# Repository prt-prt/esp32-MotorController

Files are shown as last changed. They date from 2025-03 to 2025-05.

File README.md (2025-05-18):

# ESP32 Motor Controller

A collection of motor control implementations for the ESP32-S2 Mini with DRV8833 motor driver.

## Version Overview

### v1: Basic Test
- Simple motor test sequence
- Basic forward/backward/turn movements
- No fault detection

### v2: Mode System
- Multiple movement modes (wander, rotate, test)
- Mode switching logic
- Basic error handling

### v3: Power Management
- Improved power handling
- Speed ramping
- Basic fault detection
- Reduced motor speeds

### v4: Organic Movement
- Slow, rock-like movement patterns
- Advanced fault detection
- PWM-based motor control
- Random movement generation
- Detailed debugging

### v5: Simple Forward Test
- Continuous forward movement
- Basic PWM control
- Minimal code for testing
- No mode switching or complex logic

### v6: All Directions Test
- Tests all motor directions sequentially
- Basic PWM control
- Auxiliary pin control (GPIO39)
- Cycle between directions automatically

## Hardware
- ESP32-S2 Mini (Lolin)
- DRV8833 Motor Driver
- 2 DC Motors
- Power Supply (5V recommended)

## Pin Configuration
- Motor A: GPIO11 (IN1), GPIO9 (IN2)
- Motor B: GPIO7 (IN1), GPIO5 (IN2)
- Fault Pin: GPIO12
- LED: GPIO15

## Project Structure

This project is organized into two versions:
- **v1**: Uses the ESP32-CAM and L298N motor driver (older, traditional driver)
- **v2**: Uses the ESP32-S2 Mini and DRV8833 motor driver (more efficient, modern setup)

Each version contains its own complete implementation for its respective hardware. For detailed wiring and implementation specifics, see the WIRING.md file in each subproject folder.

## Hardware Requirements

### Common Components for Both Versions
- 2-wheel drive robot car chassis with DC motors
- Jumper wires
- Small breadboard (optional, for cleaner wiring)

### Version Specific Components
- **v1**: 
  - ESP32-CAM development board
  - L298N dual H-bridge motor driver ([detailed documentation](v1/WIRING.md))
  - MP1584EN buck converter module (for power regulation)
  - Power supply for motors (battery pack/power bank)

- **v2**: 
  - Wemos ESP32-S2 Mini development board
  - DRV8833 dual H-bridge motor driver ([detailed documentation](v2/WIRING.md))
  - 5V powerbank with USB output
  - USB splitter/hub or adapter
  - USB in-line power switch (for global power control)
  - Step-up converter (boosts 5V from powerbank to 6V for motors)

### Power Supply Architecture Differences

The v1 and v2 versions use different power supply approaches:

**v1 Power Supply:**
- Battery/power source → MP1584EN buck converter → ESP32-CAM (5V)
- Battery/power source → L298N motor driver (higher voltage)

**v2 Power Supply:**
- Powerbank USB output → Global power switch → USB splitter/hub
  - First output: USB-C connection to ESP32-S2 Mini (direct connection)
  - Second output: 5V to Step-up converter → DRV8833 motor driver (6V)

The v2 setup uses a true global power switch that controls the entire system with a single switch, turning both the microcontroller and motors on/off together.

## Hardware Comparison

### Microcontroller Comparison
| Feature | v1: ESP32-CAM | v2: ESP32-S2 Mini |
|---|---|---|
| USB Connection | External programmer required | Built-in USB-C port |
| Size | Larger | Compact |
| Power Input | 5V via pins | Direct USB-C |
| Programming | Via serial adapter | Native USB |
| Unnecessary Features | Camera module | None |
| Form Factor | Less robot-friendly | Ideal for robotics |

### Motor Driver Comparison
| Feature | v1: L298N | v2: DRV8833 |
|---|---|---|
| Efficiency | ~70% | >90% |
| Control Pins | 6 total | 4 total |
| Heat Generation | High | Low |
| Size | Large | Compact |
| Control Method | Enable + Direction pins | PWM on all pins |

### Power Control Comparison
| Feature | v1 Approach | v2 Approach |
|---|---|---|
| Power Switch | Controls motors only | True global control (entire system) |
| Power Source | Separate paths | Single source with distribution |
| Wiring Complexity | More complex | Simplified with USB connectivity |
| Development Mode | ESP32 always on | System fully controlled by one switch |

For detailed pin connections, wiring diagrams, and implementation specifics, see:
- [L298N Wiring & Implementation Guide](v1/WIRING.md)
- [DRV8833 Wiring & Implementation Guide](v2/WIRING.md)

## Software Setup

This project uses PlatformIO for development and deployment:

1. Install [Visual Studio Code](https://code.visualstudio.com/)
2. Install the [PlatformIO extension](https://platformio.org/install/ide?install=vscode)
3. Clone or download this repository
4. Open either the v1 or v2 project folder in VS Code
5. Build and upload the project using PlatformIO

### V2 Programming Advantage
The v2 version with ESP32-S2 Mini can be programmed directly via USB-C connection without additional hardware, making development and testing significantly easier. During development, you can disconnect the powerbank and connect the ESP32-S2 Mini directly to your computer.

## Features

### Movement Modes

The robot car supports three different movement modes:

1. **Test Mode**: Demonstrates basic movements in a sequence
2. **Wander Mode**: Robot randomly wanders with organic movements
3. **Rotate Mode**: Robot slowly rotates around its axis

By default, the robot switches between Wander Mode and Rotate Mode every 30 seconds.

### Basic Movement Functions

The code includes the following standard movement functions:

- `moveForward(speed)`: Moves the robot forward
- `moveBackward(speed)`: Moves the robot backward
- `turnLeft(speed)`: Turns the robot left
- `turnRight(speed)`: Turns the robot right
- `stopMotors()`: Stops all motor movement

### Differential Steering

Advanced movement control is achieved through differential steering:

- `moveDifferential(leftSpeed, rightSpeed)`: Allows independent control of each wheel
- `curveLeft(leftSpeed, rightSpeed)`: Creates curved left movement
- `curveRight(leftSpeed, rightSpeed)`: Creates curved right movement

### Speed Control

All movement functions support variable speed control through PWM, with speed values ranging from 0 (stop) to 255 (full speed).

## Movement Modes in Detail

### Test Mode

Cycles through a series of basic movements to test motor functionality:
1. Forward → Stop → Backward → Stop → Left turn → Stop → Right turn → Stop

### Wander Mode

Implements organic, randomized movement with varying speeds and paths:
- Straight forward movement
- Gentle left and right curves
- Sharp left and right curves
- 180° spin turns
- Backward movement
- Random stops

### Rotate Mode

Performs a slow, controlled rotation around the robot's center:
- Rotates in a random direction (left or right)
- Changes direction every 10 seconds
- Uses reduced speed for careful rotation

## Customization

You can customize the pin assignments at the beginning of the `motor_control.cpp` file if you need to use different GPIO pins on your microcontroller.

To implement additional movement modes or alter the existing ones, refer to the corresponding mode files in the `src` directory.

## Troubleshooting

Basic troubleshooting tips are included in the WIRING.md file for each version:
- [L298N Troubleshooting](v1/WIRING.md#troubleshooting)
- [DRV8833 Troubleshooting](v2/WIRING.md#troubleshooting)

## Project Structure

For each version (v1 and v2):
- `platformio.ini`: PlatformIO configuration
- `WIRING.md`: Detailed wiring and implementation documentation
- `include/motor_control.h`: Header file for motor control functions
- `include/movement_modes.h`: Defines the movement modes enum
- `include/test_mode.h`: Header for test mode
- `include/wander_mode.h`: Header for wander mode
- `include/rotate_mode.h`: Header for rotate mode
- `src/motor_control.cpp`: Motor control functions implementation
- `src/main.cpp`: Main program with setup, loop, and mode switching logic
- `src/test_mode.cpp`: Test mode implementation
- `src/wander_mode.cpp`: Wander mode implementation with organic movement
- `src/rotate_mode.cpp`: Rotate mode implementation

## License

This project is open source and available under the MIT License.

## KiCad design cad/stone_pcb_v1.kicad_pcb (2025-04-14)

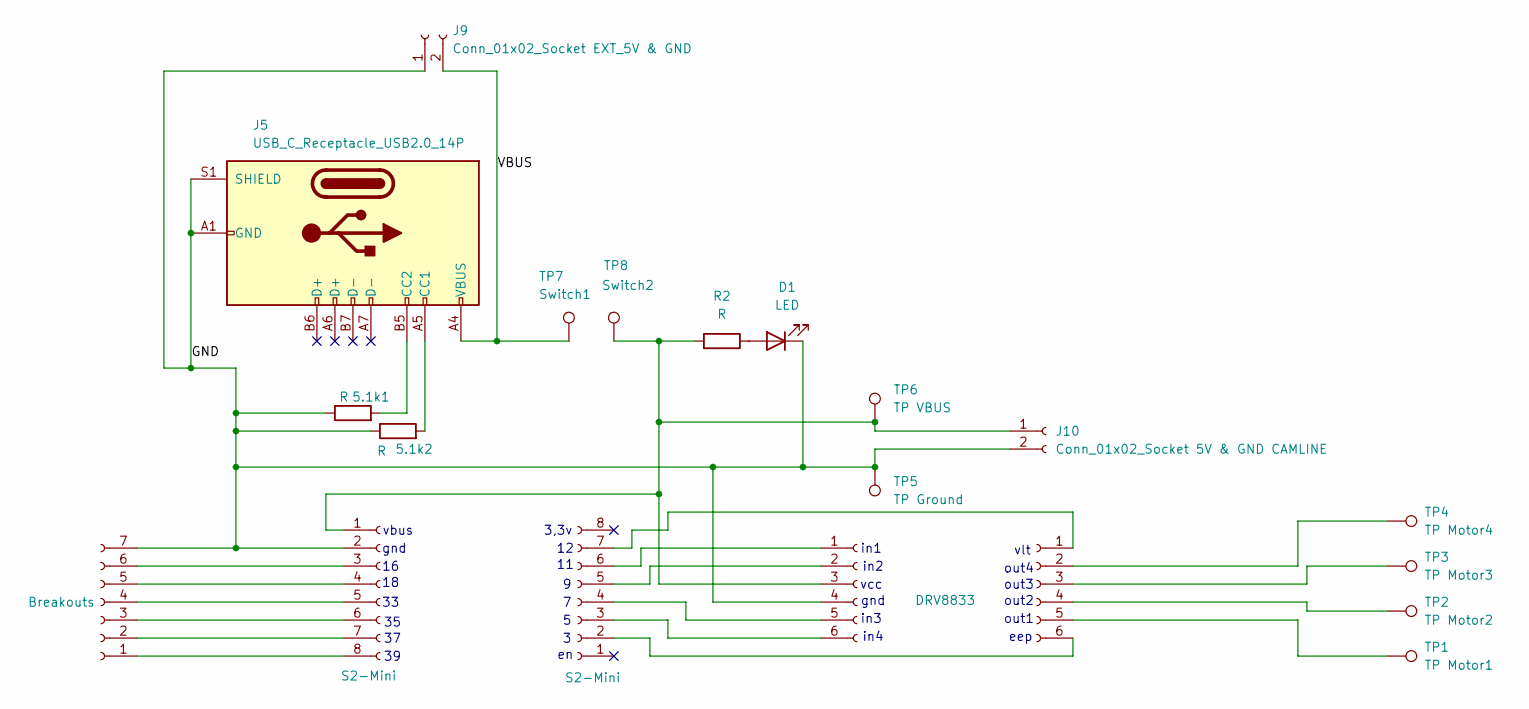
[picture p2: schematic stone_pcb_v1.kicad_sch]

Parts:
5.1k1, 5.1k2: R; R_Axial_DIN0204_L3.6mm_D1.6mm_P7.62mm_Horizontal
D1: LED; LED_D5.0mm
J1: PinSocket_1x06_P2.54mm_Vertical
J2: DRV8833; PinSocket_1x06_P2.54mm_Vertical
J5: USB_C_Receptacle_USB2.0_14P; USB_C_Receptacle_HRO_TYPE-C-31-M-12
J6, J8: S2-Mini; PinSocket_1x08_P2.54mm_Vertical
J7: Breakouts; PinSocket_1x07_P2.54mm_Vertical
J9: Conn_01x02_Socket EXT_5V & GND; PinSocket_1x02_P2.54mm_Vertical
J10: Conn_01x02_Socket 5V & GND CAMLINE; PinSocket_1x02_P2.54mm_Vertical
R2: R; R_Axial_DIN0204_L3.6mm_D1.6mm_P7.62mm_Horizontal
TP1: TP Motor1; TestPoint_Pad_D2.0mm
TP2: TP Motor2; TestPoint_Pad_D2.0mm
TP3: TP Motor3; TestPoint_Pad_D2.0mm
TP4: TP Motor4; TestPoint_Pad_D2.0mm
TP5: TP Ground; TestPoint_Pad_D2.0mm
TP6: TP VBUS; TestPoint_Pad_D2.0mm
TP7: Switch1; TestPoint_Pad_D2.0mm
TP8: Switch2; TestPoint_Pad_D2.0mm

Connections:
/GND: 5.1k1.1, 5.1k2.1, D1.1 (K), J2.4, J5.A1 (GND), J5.A12 (GND), J5.B1 (GND), J5.B12 (GND), J5.S1 (SHIELD), J6.2, J7.7, J9.1, J10.2, TP5.1
/VBUS: J5.A4 (VBUS), J5.A9 (VBUS), J5.B4 (VBUS), J5.B9 (VBUS), J9.2, TP7.1
unnamed: D1.2 (A), R2.1
unnamed: J1.1, J8.7
unnamed: J1.2, TP4.1
unnamed: J1.3, TP3.1
unnamed: J1.4, TP2.1
unnamed: J1.5, TP1.1
unnamed: J1.6, J8.2
unnamed: J2.1, J8.6
unnamed: J2.2, J8.5
unnamed: J2.5, J8.4
unnamed: J2.6, J8.3
unnamed: 5.1k2.2, J5.A5 (CC1)
unnamed: 5.1k1.2, J5.B5 (CC2)
unnamed: J6.3, J7.6
unnamed: J6.4, J7.5
unnamed: J6.5, J7.4
unnamed: J6.6, J7.3
unnamed: J6.7, J7.2
unnamed: J6.8, J7.1
unnamed: J2.3, J6.1, J10.1, R2.2, TP6.1, TP8.1

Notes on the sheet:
out2
in4
eep
in2
gnd
in1
vbus
out3
vlt
out4
3,3v
in3
out1
vcc

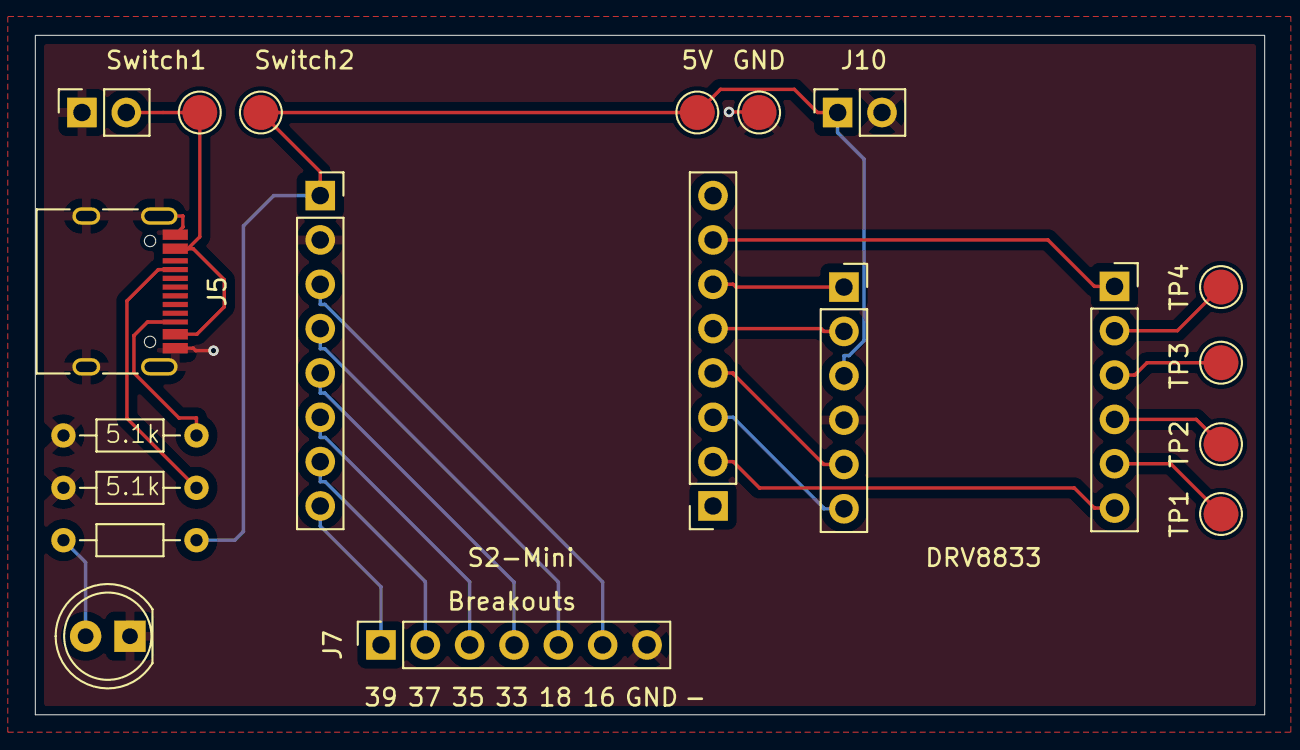
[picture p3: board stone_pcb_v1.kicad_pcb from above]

Board: 2 copper layers, 70.4 x 38.9 mm, 20 parts (0 on the bottom side), 22 nets.

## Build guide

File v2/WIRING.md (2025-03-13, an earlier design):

# DRV8833 Motor Driver Implementation with ESP32-S2 Mini

This document provides detailed information about the DRV8833 motor driver implementation used in the v2 version of the ESP32 Robot Car Controller project, using a Wemos ESP32-S2 Mini as the microcontroller.

## Hardware Components

- **Wemos ESP32-S2 Mini** microcontroller
- **DRV8833** dual H-bridge motor driver breakout board
- **Step-up converter** (5V to 6V)
- **SPST toggle switch** (for global power control)
- **Powerbank** with USB output
- **USB splitter cable or adapter** (to split USB power after the switch)
- **DC motors** (2x)
- **Jumper wires and connectors**

## ESP32-S2 Mini Overview

The Wemos ESP32-S2 Mini offers significant advantages for this robot project:

- Built-in USB-C port for programming and power
- Small form factor (ideal for compact robots)
- Native USB support
- Multiple GPIO pins available for motor control
- 3.3V logic level
- Built-in power regulation
- Low power consumption

## DRV8833 Motor Driver Overview

The DRV8833 is a modern dual H-bridge motor driver that can control two DC motors independently. It offers significant advantages over older drivers like the L298N in terms of efficiency, size, and power consumption.

### Key Characteristics
- Dual H-bridge motor driver
- Operating voltage: 2.7V to 10.8V
- Maximum continuous current: 1.5A per channel (2A peak)
- PWM speed and direction control through the same pins
- High efficiency (>90%)
- Low heat generation
- Small physical footprint
- Built-in protection features (overcurrent, overtemperature, undervoltage)

## DRV8833 Board Pinout

This implementation uses a DRV8833 breakout board with the following pinout:

| Pin Label | Function |
|---|---|
| VCC | Power input for both motors and logic (connect 6V from step-up converter) |
| GND | Ground connection |
| IN1 | Input control for motor A direction 1 |
| IN2 | Input control for motor A direction 2 |
| IN3 | Input control for motor B direction 1 |
| IN4 | Input control for motor B direction 2 |
| OUT1 | Output to motor A terminal 1 |
| OUT2 | Output to motor A terminal 2 |
| OUT3 | Output to motor B terminal 1 |
| OUT4 | Output to motor B terminal 2 |
| SLEEP | Sleep mode control (tie to VCC for always-on or connect to GPIO for software control) |

## Pin Configuration

### Control Pins
| ESP32-S2 Mini GPIO | DRV8833 Pin | Function |
|---|---|---|
| GPIO7 | IN1 | PWM control for left motor direction 1 |
| GPIO8 | IN2 | PWM control for left motor direction 2 |
| GPIO9 | IN3 | PWM control for right motor direction 1 |
| GPIO10 | IN4 | PWM control for right motor direction 2 |

*Note: The exact GPIO numbers should be adjusted based on your specific board layout and requirements.*

### Power Connections
| Power Source | Connected To | Function |
|---|---|---|
| Powerbank USB output | Global toggle switch | Main power input for entire system |
| Toggle switch output | USB splitter | Distributes power to both systems |
| USB splitter - first output | ESP32-S2 Mini USB-C | Power for microcontroller |
| USB splitter - second output | 5V to Step-up converter | Input for motor power circuit |
| Step-up converter output (6V) | DRV8833 VCC | Power supply for motor driver (6V recommended) |
| ESP32-S2 Mini GPIO (optional) | DRV8833 SLEEP pin | Software control of driver power state |
| GND connections | Common ground | All grounds must be connected together |

## Power Supply Architecture

This implementation uses a true global power control approach:

1. **Powerbank** serves as the single power source:
   - USB output goes to the global toggle switch

2. **Global Power Switch**:
   - SPST toggle switch placed between the powerbank and all power consumers
   - Provides master on/off control for the entire system
   - When off, both the ESP32-S2 Mini and motors are powered down
   - When on, power flows to both the ESP32-S2 Mini and the step-up converter

3. **USB Power Distribution**:
   - After the switch, a USB splitter/adapter divides power to:
     1. ESP32-S2 Mini via USB-C connector (for both power and programming)
     2. Step-up converter input (via USB power extraction)

4. **Step-up Converter**:
   - Boosts the 5V from the USB power to 6V
   - Powers the DRV8833 motor driver through its VCC pin

This architecture provides simplified control with a single switch while maintaining clean, separate power paths for the sensitive microcontroller and the more demanding motors.

## Detailed Wiring Diagram

```
Powerbank
│
└── USB output ──── Global Toggle Switch ──── USB Splitter/Hub
                                               │
                                               ├─── USB-C to ESP32-S2 Mini
                                               │
                                               └─── USB power extraction
                                                    │
                                                    │ (5V + GND)
                                                    │
                                                    └─── Step-up Converter
                                                         │
                                                         │ (6V output)
                                                         │
                                                         └─── VCC (DRV8833)

ESP32-S2 Mini            DRV8833
│                        │
├── GPIO7 ────────────── IN1
│                        │
├── GPIO8 ────────────── IN2
│                        │
├── GPIO9 ────────────── IN3
│                        │
├── GPIO10 ───────────── IN4
│                        │
└── GND ─────────────────┼─── GND
                         │
                         ├─── OUT1 ─── Left Motor Terminal 1
                         │
                         ├─── OUT2 ─── Left Motor Terminal 2
                         │
                         ├─── OUT3 ─── Right Motor Terminal 1
                         │
                         └─── OUT4 ─── Right Motor Terminal 2

All GND connections must be common between:
- ESP32-S2 Mini
- DRV8833
- Step-up converter
- Powerbank negative output
```

## Implementing the Global Power Switch

There are two recommended approaches for implementing the global power switch:

### Option 1: USB Power Switch (Preferred)
- Use a dedicated USB power switch that handles all 4 USB lines
- This allows for data connectivity when needed
- Examples: USB in-line switch or USB power switch module

### Option 2: DIY Approach
- Use a SPST toggle switch placed in the USB power line (VBUS/red wire only)
- Cut only the red wire in a USB cable and connect the toggle switch
- Ensure the switch is rated for at least 2-3A
- Leave the data lines (D+/D-) and ground wire intact

## Power Supply Considerations

### Powerbank Selection
- Choose a powerbank with at least 2A output capability 
- Standard USB output will be split between ESP32-S2 Mini and the motor circuit
- For longer run time, select a powerbank with higher capacity (10,000mAh+)
- Some powerbanks may turn off automatically with low current draw, so test before final implementation

### Global Power Switch
- SPST (Single Pole, Single Throw) toggle switch for DIY approach
- USB power switch for cleaner implementation 
- Should be rated for at least 2-3A
- Position the switch in an easily accessible location on the robot
- Provides convenient on/off control for the entire system

### USB Splitter/Power Distribution
- Use a high-quality USB splitter or hub that can handle 2A+ total current
- For DIY approach, you can extract 5V/GND from a USB breakout board or adapter
- Ensure all power connections use adequately sized wires

### Step-up Converter for Motors
- Converts 5V to 6V for optimal motor performance
- The DRV8833 works well with 6V for small DC motors
- Higher voltage provides better torque and speed
- Efficiency is typically around 85-90%
- Must be able to handle the peak current of both motors running simultaneously

### ESP32-S2 Mini Power
- Powered directly via USB-C port from the USB splitter
- Has built-in power regulation
- The power switch controls both ESP32-S2 Mini and motors for true global control

### Common Ground Connection
- All ground connections must be tied together
- This ensures proper signal transmission and prevents floating reference issues
- Create a central ground point or "star ground" for all components

## DRV8833 Control Logic

The DRV8833 uses a more streamlined approach to motor control compared to traditional drivers:

1. **Both Direction and Speed Control**: Each motor requires two PWM pins (IN1/IN2 for left motor, IN3/IN4 for right motor)
2. **No Separate Enable Pins**: Direction and speed are controlled by the PWM duty cycle on the input pins

### Motor Control Logic
| Motor Function | IN1/IN3 | IN2/IN4 | Result |
|---|---|---|---|
| Forward | PWM | 0 | Motor rotates forward at speed proportional to PWM |
| Backward | 0 | PWM | Motor rotates backward at speed proportional to PWM |
| Coast (free) | 0 | 0 | Motor is disconnected (free rotation) |
| Brake (lock) | 1 | 1 | Motor terminals are shorted (active braking) |

### Robot Movement Control
| Robot Movement | Left Motor | Right Motor |
|---|---|---|
| Forward | IN1=PWM, IN2=0 | IN3=PWM, IN4=0 |
| Backward | IN1=0, IN2=PWM | IN3=0, IN4=PWM |
| Turn Left | IN1=0, IN2=PWM | IN3=PWM, IN4=0 |
| Turn Right | IN1=PWM, IN2=0 | IN3=0, IN4=PWM |
| Stop | IN1=0, IN2=0 | IN3=0, IN4=0 |

## Power Management Using SLEEP Pin

The DRV8833 motor driver features a SLEEP pin that can be used for advanced power management. There are two ways to control this pin:

### Option 1: Always-On Configuration (Fixed Wiring)
- Connect the SLEEP pin directly to the VCC pin or to 3.3V from the ESP32
- The motor driver will always be enabled when power is supplied
- Simplest configuration but doesn't allow for software-controlled power saving

### Option 2: Software Control for Power Saving (Recommended)
- Connect the SLEEP pin to an available GPIO pin on the ESP32-S2 Mini
- Use software control to enable/disable the motor driver when needed
- Significantly reduces power consumption when motors are idle

#### Implementation for Software Control:

1. **Hardware Connection**:
   - Connect the SLEEP pin from the DRV8833 to an available GPIO pin (e.g., GPIO5)
   - Make sure your ground connections are solid

2. **Software Implementation**:
   ```cpp
   const int SLEEP_PIN = 5; // Choose any available GPIO pin
   
   void setup() {
     pinMode(SLEEP_PIN, OUTPUT);
     digitalWrite(SLEEP_PIN, HIGH); // Initially enable the driver
   }
   
   // Function to put the motor driver to sleep (low power mode)
   void disableMotorDriver() {
     digitalWrite(SLEEP_PIN, LOW); // Driver enters sleep mode
   }
   
   // Function to wake up the motor driver
   void enableMotorDriver() {
     digitalWrite(SLEEP_PIN, HIGH); // Driver is active
     delay(1); // Small delay for wake-up time
   }
   ```

3. **Power Saving Strategy**:
   - Enable the driver only when motors need to be used
   - Disable the driver during extended idle periods
   - Can be triggered by inactivity timers or low battery conditions

4. **Important Notes**:
   - When in sleep mode (SLEEP pin LOW), the motor outputs are disabled regardless of IN1-IN4 states
   - The driver will respond to the current IN1-IN4 pin states immediately when woken up
   - The sleep mode reduces power consumption to microamps, significantly extending battery life
   - Always enable the driver before attempting to control the motors

This software-controlled approach provides the best balance between functionality and power efficiency, making it ideal for battery-powered robot applications.

## Assembly Instructions

1. **Prepare the components**:
   - ESP32-S2 Mini
   - DRV8833 driver board
   - Step-up converter
   - Toggle switch or USB power switch
   - USB splitter/adapter
   - Powerbank
   - Jumper wires

2. **Prepare the power switch**:
   - Option 1: Install the USB power switch in-line with the USB cable from the powerbank
   - Option 2: Cut the red wire in a USB cable and connect the toggle switch

3. **Mount the components**:
   - Secure all components to the robot chassis
   - Position the power switch in an easily accessible location
   - Ensure motors are properly installed on the chassis

4. **Connect the power circuit**:
   - Connect the powerbank's USB output to the power switch
   - Connect the power switch output to the USB splitter
   - Connect one output from the splitter to the ESP32-S2 Mini's USB-C port
   - Extract 5V/GND from the second output and connect to the step-up converter input
   - Connect the step-up converter's 6V output to VCC on the DRV8833
   - Connect all ground lines together (powerbank, ESP32-S2 Mini, step-up converter, DRV8833)

5. **Connect the control circuit**:
   - Connect GPIO7 on ESP32-S2 Mini to IN1 on DRV8833
   - Connect GPIO8 on ESP32-S2 Mini to IN2 on DRV8833
   - Connect GPIO9 on ESP32-S2 Mini to IN3 on DRV8833
   - Connect GPIO10 on ESP32-S2 Mini to IN4 on DRV8833

6. **Connect the motors**:
   - Connect left motor to OUT1 and OUT2 on DRV8833
   - Connect right motor to OUT3 and OUT4 on DRV8833

7. **Test the circuit**:
   - Power on the circuit using the global power switch
   - Verify that the ESP32-S2 Mini powers up correctly
   - Check voltage levels at the DRV8833 VCC pin (should be approximately 6V)

## Advantages of This Setup

1. **True global control**: 
   - One switch powers the entire system on or off
   - No need to disconnect the powerbank when not in use
   - Prevents battery drain during storage

2. **Simplified power management**:
   - Single power source (powerbank)
   - Clean power distribution to all components
   - Separate power paths for ESP32-S2 Mini and motors after the split

3. **Enhanced development experience**:
   - Native USB support when connected to computer
   - When programming/debugging, can disconnect the powerbank and use computer USB
   - Single switch operation for field testing

4. **Compact design**:
   - ESP32-S2 Mini has a smaller footprint than ESP32-CAM
   - Better suited for small robot platforms
   - No unnecessary camera module taking up space

## Troubleshooting

### System Not Powering Up
- Check if the global power switch is in the ON position
- Verify all USB connections are secure
- Check the powerbank has sufficient charge
- Test the power switch continuity with a multimeter

### ESP32-S2 Mini Not Powering Up
- Check all USB connections in the power path
- Try a different USB cable
- Make sure the USB splitter is functioning correctly
- Verify the powerbank has sufficient charge

### Motors Not Responding
- Verify power connections (VCC and GND on DRV8833)
- Ensure the step-up converter is outputting approximately 6V
- Confirm motor connections to OUT and GND pins
- Verify control pin connections between ESP32-S2 Mini and DRV8833

### Motors Running In Wrong Direction
- Swap the motor terminal connections (OUT1/OUT2 or OUT3/OUT4)
- Or modify the control logic in the code to invert the direction

### Inconsistent Motor Behavior
- Check all ground connections are properly connected together
- Verify the step-up converter is providing stable voltage
- Ensure the USB splitter can provide sufficient current

### Electrical Noise Issues
- Keep signal wires away from motor wires where possible
- Add 0.1μF ceramic capacitors across motor terminals if experiencing noise issues
- Consider adding ferrite beads on motor wires

### Power Management Issues
- If powerbank auto-shuts off, look for a model with "always on" capability
- For longer run times, consider a powerbank with higher capacity (10,000mAh+)
- If the system resets when motors start, ensure USB splitter and powerbank can provide sufficient current

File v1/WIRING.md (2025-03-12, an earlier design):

# L298N Motor Driver Implementation Details

This document provides detailed information about the L298N motor driver implementation used in the v1 version of the ESP32 Robot Car Controller project.

## L298N Motor Driver Overview

The L298N is a traditional dual H-bridge motor driver that can control two DC motors independently. It has been widely used in robotics projects for many years.

### Key Characteristics
- Dual H-bridge motor driver
- Operating voltage: 5-35V
- Maximum current: 2A per channel
- Separate pins for direction control and speed control
- Lower efficiency (~70%)
- Higher heat generation (requires heatsink)
- Larger physical size

## Pin Configuration

The L298N motor driver requires 6 pins to control two motors:

### Control Pins
| ESP32 GPIO | L298N Pin | Function |
|---|---|---|
| GPIO2 | IN1 | Direction control for left motor |
| GPIO12 | IN2 | Direction control for left motor |
| GPIO14 | ENA | PWM speed control for left motor |
| GPIO15 | IN3 | Direction control for right motor |
| GPIO13 | IN4 | Direction control for right motor |
| GPIO16 | ENB | PWM speed control for right motor |

### Power Connections
| Power Source | L298N Pin | Function |
|---|---|---|
| Battery + | +12V | Motor power input (6-12V recommended) |
| Battery - | GND | Ground connection |
| 5V | +5V | Logic power (jumper should be removed if using external 5V) |

## Detailed Wiring Diagram

```
Power Bank/Battery
│
├── + ──┬─── +12V (L298N Motor Power)
│       │
│       └─── VIN+ (MP1584EN Input)
│
└── - ──┬─── GND (L298N)
        │
        └─── VIN- (MP1584EN Input)

MP1584EN Buck Converter (Optional for ESP32 power)
│
├── VOUT+ ─── 5V (ESP32-CAM)
│
└── VOUT- ─── GND (ESP32-CAM)

ESP32-CAM                L298N
│                        │
├── GPIO2 ───────────── IN1
│                        │
├── GPIO12 ──────────── IN2
│                        │
├── GPIO14 ──────────── ENA
│                        │
├── GPIO15 ──────────── IN3
│                        │
├── GPIO13 ──────────── IN4
│                        │
├── GPIO16 ──────────── ENB
│                        │
└── GND ─────────────── GND
                         │
                         ├── OUT1 ─── Left Motor Terminal 1
                         │
                         ├── OUT2 ─── Left Motor Terminal 2
                         │
                         ├── OUT3 ─── Right Motor Terminal 1
                         │
                         └── OUT4 ─── Right Motor Terminal 2
```

## L298N Control Logic

The L298N driver uses a different control approach than modern drivers like the DRV8833:

1. **Direction Control**: The direction of each motor is controlled by setting the corresponding input pins (IN1/IN2 for left motor, IN3/IN4 for right motor)
2. **Speed Control**: The speed of each motor is controlled by applying a PWM signal to the enable pins (ENA for left motor, ENB for right motor)

### Direction Control Logic
| Motor Direction | IN1/IN3 | IN2/IN4 |
|---|---|---|
| Forward | HIGH | LOW |
| Backward | LOW | HIGH |
| Stop | LOW | LOW |
| Brake (lock) | HIGH | HIGH |

### Robot Movement Control
| Robot Movement | Left Motor | Right Motor | IN1 | IN2 | IN3 | IN4 | ENA | ENB |
|---|---|---|-----|-----|-----|-----|-----|-----|
| Forward | Forward | Forward | HIGH| LOW | HIGH| LOW | PWM | PWM |
| Backward | Backward | Backward | LOW | HIGH| LOW | HIGH| PWM | PWM |
| Turn Left | Backward | Forward | LOW | HIGH| HIGH| LOW | PWM | PWM |
| Turn Right | Forward | Backward | HIGH| LOW | LOW | HIGH| PWM | PWM |
| Stop | Stop | Stop | LOW | LOW | LOW | LOW | LOW | LOW |

## Implementation Notes

### PWM Configuration
The implementation uses the ESP32's ledc functions for PWM generation:
- PWM Frequency: 5000 Hz
- PWM Resolution: 8-bit (0-255)
- PWM Channels: Channel 0 for ENA, Channel 1 for ENB

### Code Structure
The motor control implementation follows these key principles:
1. Direction pins (IN1, IN2, IN3, IN4) are configured as standard digital outputs
2. Enable pins (ENA, ENB) are configured as PWM outputs
3. High-level functions abstract the pin control details

### Key Functions

#### Motor Control
```cpp
// Set left motor speed and direction
void setMotorA(int speed, bool forward) {
  // Constrain speed to valid range
  speed = constrain(speed, MIN_SPEED, MAX_SPEED);
  
  if (forward) {
    digitalWrite(IN1, HIGH);
    digitalWrite(IN2, LOW);
  } else {
    digitalWrite(IN1, LOW);
    digitalWrite(IN2, HIGH);
  }
  
  // Set speed via PWM on enable pin
  ledcWrite(PWM_CHANNEL_ENA, speed);
}

// Set right motor speed and direction
void setMotorB(int speed, bool forward) {
  // Constrain speed to valid range
  speed = constrain(speed, MIN_SPEED, MAX_SPEED);
  
  if (forward) {
    digitalWrite(IN3, HIGH);
    digitalWrite(IN4, LOW);
  } else {
    digitalWrite(IN3, LOW);
    digitalWrite(IN4, HIGH);
  }
  
  // Set speed via PWM on enable pin
  ledcWrite(PWM_CHANNEL_ENB, speed);
}
```

### Differential Steering
The implementation supports differential steering, allowing for more organic and precise movements:
```cpp
// Function to move with different speeds for each wheel
// Positive values: forward, Negative values: backward
void moveDifferential(int leftSpeed, int rightSpeed) {
  // Determine direction and speed for left motor
  bool leftForward = (leftSpeed >= 0);
  int absLeftSpeed = abs(leftSpeed);
  
  // Determine direction and speed for right motor
  bool rightForward = (rightSpeed >= 0);
  int absRightSpeed = abs(rightSpeed);
  
  // Set motors
  setMotorA(absLeftSpeed, leftForward);
  setMotorB(absRightSpeed, rightForward);
}
```

## Limitations and Considerations

### Efficiency
The L298N has a voltage drop of approximately 1.5V, which means:
- Less efficient than modern drivers (~70% efficiency)
- Higher heat generation requiring a heatsink
- Reduced effective voltage to the motors (e.g., with a 7.4V battery, motors receive ~5.9V)

### Current Limitations
The L298N can provide up to 2A per channel, which is sufficient for most small to medium DC motors, but may not be enough for larger motors.

### Size Considerations
The L298N is larger than modern alternatives, which may be a consideration for space-constrained projects.

## Troubleshooting

### Motors Not Responding
- Check all control pin connections
- Verify power connections
- Ensure 5V logic power is available
- Confirm motor connections

### Motors Running In Wrong Direction
- Swap the motor terminal connections (OUT1/OUT2 or OUT3/OUT4)
- Or modify the control logic in the code to invert the direction

### Weak Motor Power
- Check battery voltage
- Ensure adequate power supply capacity
- Consider the voltage drop across the L298N
- Verify PWM signals on enable pins

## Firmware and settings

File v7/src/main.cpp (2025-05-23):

#include <Arduino.h>
#include "motor_control.h"
#include "movement_modes.h"

// Timing
const unsigned long BLINK_INTERVAL = 1000;      // 1 second blink interval for pin 39

// Capacitor charging delays
const unsigned long INITIAL_CAP_CHARGE_DELAY = 15000;  // 15 seconds for initial capacitor charging

// Program state
unsigned long lastBlinkTime = 0;
bool auxPinState = false;
bool initialStartupComplete = false;

void blinkLED(int times, int onTime = 200, int offTime = 200) {
  for (int i = 0; i < times; i++) {
    digitalWrite(LED_PIN, HIGH);
    delay(onTime);
    digitalWrite(LED_PIN, LOW);
    delay(offTime);
  }
}

void setup() {
  // Initialize Serial for debugging
  Serial.begin(115200);
  delay(500); // Give serial time to initialize
  Serial.println("\n\n----- ESP32 Motor Controller v7 with Movement Modes -----");
  
  // Configure LED and AUX pins
  pinMode(LED_PIN, OUTPUT);
  pinMode(AUX_PIN, OUTPUT);
  digitalWrite(AUX_PIN, LOW);
  
  Serial.println("Starting up - blinking LED 7 times");
  // Blink LED 7 times to indicate version 7
  blinkLED(7);
  
  Serial.println("Initializing motors");
  // Initialize motors
  setupMotors();
  
  Serial.println("Initial capacitor charging delay starting");
  Serial.print("Waiting for ");
  Serial.print(INITIAL_CAP_CHARGE_DELAY);
  Serial.println(" ms");
  
  // Initial capacitor charging delay
  // This gives time for both 2200uF capacitors to charge up
  delay(INITIAL_CAP_CHARGE_DELAY);
  Serial.println("Initial capacitor charging complete");
  
  Serial.println("Initializing movement modes");
  // Initialize movement modes
  initMovementModes();
  
  // Start with motors stopped
  setDirection(STOP);
  
  // Mark initial startup as complete
  initialStartupComplete = true;
  Serial.println("Setup complete - entering main loop");
}

void loop() {
  unsigned long currentTime = millis();
  
  // Continuously blink AUX_PIN (GPIO39) regardless of motor state
  if (currentTime - lastBlinkTime >= BLINK_INTERVAL) {
    lastBlinkTime = currentTime;
    
    // Toggle AUX_PIN state
    auxPinState = !auxPinState;
    digitalWrite(AUX_PIN, auxPinState);
  }

  // Update current movement mode - this handles all movement patterns
  updateCurrentMode();
}

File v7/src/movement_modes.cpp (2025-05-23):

#include <Arduino.h>
#include "movement_modes.h"
#include "motor_control.h"

// Global state
static MovementMode* currentMode = nullptr;
static int currentModeIndex = 0;
static int currentDurationIndex = 0;
static unsigned long modeStartTime = 0;
static unsigned long lastMovementUpdate = 0;
static unsigned long lastAuxPinUpdate = 0;
static bool auxPinState = false;
static bool inRestPeriod = false;
static int restDuration = 0;

// Define all movement modes
static MovementMode movementModes[] = {
  {
    "Spin",
    spinPattern,
    auxPinBlink,
    100,    // Update movement every 100ms
    100,    // Update aux pin every 100ms
    100     // Keep aux pin on for 100ms
  },
  {
    "Wander",
    wanderPattern,
    auxPinRandom,
    500,    // Update movement every 500ms
    200,    // Update aux pin every 200ms
    50      // Keep aux pin on for 50ms
  },
  {
    "Pulse",
    pulsePattern,
    auxPinPulse,
    1000,   // Update movement every 1000ms
    500,    // Update aux pin every 500ms
    200     // Keep aux pin on for 200ms
  },
  {
    "Circle",
    circlePattern,
    auxPinWave,
    200,    // Update movement every 200ms
    100,    // Update aux pin every 100ms
    150     // Keep aux pin on for 150ms
  },
  {
    "Zigzag",
    zigzagPattern,
    auxPinBlink,
    300,    // Update movement every 300ms
    150,    // Update aux pin every 150ms
    75      // Keep aux pin on for 75ms
  },
  {
    "Stop",
    stopPattern,
    auxPinOff,
    1000,   // Update movement every 1000ms
    1000,   // Update aux pin every 1000ms
    0       // Keep aux pin off
  },
  {
    "Rest",
    restPattern,
    auxPinOff,
    2000,   // Update movement every 2000ms (just to check status)
    2000,   // Update aux pin every 2000ms
    0       // Keep aux pin off
  }
};

int getRandomRestDuration() {
  return random(MIN_REST_DURATION, MAX_REST_DURATION + 1);
}

void initMovementModes() {
  // Initialize random seed
  randomSeed(analogRead(0));
  
  // Select initial mode and duration
  currentModeIndex = 0; // Start with the first mode (Spin)
  currentDurationIndex = 0; // Start with the first duration (5 seconds)
  currentMode = &movementModes[currentModeIndex];
  modeStartTime = millis();
  inRestPeriod = false;
  
  Serial.println("Movement modes initialized");
  Serial.print("Initial mode: ");
  Serial.print(currentMode->name);
  Serial.print(", Duration: ");
  Serial.print(DURATION_OPTIONS[currentDurationIndex]);
  Serial.println(" seconds");
}

void selectNextMode() {
  if (inRestPeriod) {
    // Coming out of rest, select next active mode
    inRestPeriod = false;
    currentModeIndex = (currentModeIndex + 1) % (NUM_MODES - 1); // Skip the REST mode
    currentMode = &movementModes[currentModeIndex];
    
    // Select next duration
    currentDurationIndex = (currentDurationIndex + 1) % NUM_DURATION_OPTIONS;
  } else {
    // Entering rest period
    inRestPeriod = true;
    currentModeIndex = MODE_REST;
    currentMode = &movementModes[currentModeIndex];
    
    // Random rest duration
    restDuration = getRandomRestDuration();
  }
  
  // Reset timers
  modeStartTime = millis();
  lastMovementUpdate = millis();
  lastAuxPinUpdate = millis();
  
  Serial.println("\n--- Mode Change ---");
  Serial.print("New mode: ");
  Serial.print(currentMode->name);
  
  if (inRestPeriod) {
    Serial.print(", Rest Duration: ");
    Serial.print(restDuration);
    Serial.println(" seconds");
  } else {
    Serial.print(", Duration: ");
    Serial.print(DURATION_OPTIONS[currentDurationIndex]);
    Serial.println(" seconds");
  }
  
  Serial.print("Movement interval: ");
  Serial.print(currentMode->movementInterval);
  Serial.print("ms, Aux pin interval: ");
  Serial.print(currentMode->auxPinInterval);
  Serial.println("ms");
}

void updateCurrentMode() {
  unsigned long currentTime = millis();
  
  // Check if it's time to change mode
  if (inRestPeriod) {
    if (currentTime - modeStartTime >= (restDuration * 1000)) {
      Serial.print("Rest period ended after ");
      Serial.print(restDuration);
      Serial.println(" seconds");
      selectNextMode();
      return;
    }
  } else if (currentTime - modeStartTime >= (DURATION_OPTIONS[currentDurationIndex] * 1000)) {
    Serial.print("Mode timeout reached after ");
    Serial.print((currentTime - modeStartTime) / 1000);
    Serial.println(" seconds");
    selectNextMode();
    return;
  }
  
  // Update movement if needed
  if (currentTime - lastMovementUpdate >= currentMode->movementInterval) {
    lastMovementUpdate = currentTime;
    Serial.print("Updating movement pattern: ");
    Serial.println(currentMode->name);
    currentMode->movementFunction();
  }
  
  // Update aux pin if needed
  if (currentTime - lastAuxPinUpdate >= currentMode->auxPinInterval) {
    lastAuxPinUpdate = currentTime;
    Serial.print("Updating aux pin behavior for mode: ");
    Serial.println(currentMode->name);
    currentMode->auxPinFunction();
  }
}

MovementMode* getCurrentMode() {
  return currentMode;
}

int getCurrentModeDuration() {
  if (inRestPeriod) {
    return restDuration;
  }
  return DURATION_OPTIONS[currentDurationIndex];
}

unsigned long getModeStartTime() {
  return modeStartTime;
}

// Movement pattern implementations
void spinPattern() {
  // Alternate between left and right turns
  static bool turnLeft = true;
  Serial.print("Spin pattern: turning ");
  Serial.println(turnLeft ? "LEFT" : "RIGHT");
  setDirection(turnLeft ? TURN_LEFT : TURN_RIGHT);
  turnLeft = !turnLeft;
}

void wanderPattern() {
  // Randomly choose a direction
  int direction = random(4);  // 0-3
  const char* directionStr;
  switch (direction) {
    case 0: setDirection(FORWARD); directionStr = "FORWARD"; break;
    case 1: setDirection(BACKWARD); directionStr = "BACKWARD"; break;
    case 2: setDirection(TURN_LEFT); directionStr = "TURN_LEFT"; break;
    case 3: setDirection(TURN_RIGHT); directionStr = "TURN_RIGHT"; break;
  }
  Serial.print("Wander pattern: random direction = ");
  Serial.println(directionStr);
}

void pulsePattern() {
  // Alternate between forward and backward
  static bool forward = true;
  Serial.print("Pulse pattern: ");
  Serial.println(forward ? "FORWARD" : "BACKWARD");
  setDirection(forward ? FORWARD : BACKWARD);
  forward = !forward;
}
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

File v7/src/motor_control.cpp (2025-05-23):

#include <Arduino.h>
#include "motor_control.h"

// PWM configuration
const int PWM_FREQ = 500;
const int PWM_RESOLUTION = 8;  // 8-bit resolution (0-255)

const int MOTOR_SPEED_ACTUAL = 200;  // Reduced for avoiding brownouts

void setupMotors() {
  Serial.println("Setting up motors with:");
  Serial.print("PWM Frequency: ");
  Serial.print(PWM_FREQ);
  Serial.print("Hz, Resolution: ");
  Serial.print(PWM_RESOLUTION);
  Serial.print(" bits, Motor Speed: ");
  Serial.println(MOTOR_SPEED_ACTUAL);
  
  // Configure PWM
  ledcSetup(0, PWM_FREQ, PWM_RESOLUTION);  // Channel 0 for Motor A IN1
  ledcSetup(1, PWM_FREQ, PWM_RESOLUTION);  // Channel 1 for Motor A IN2
  ledcSetup(2, PWM_FREQ, PWM_RESOLUTION);  // Channel 2 for Motor B IN1
  ledcSetup(3, PWM_FREQ, PWM_RESOLUTION);  // Channel 3 for Motor B IN2
  
  // Attach PWM channels to pins
  Serial.println("Attaching PWM channels to pins:");
  Serial.print("Motor A: IN1=");
  Serial.print(MOTOR_A_IN1);
  Serial.print(", IN2=");
  Serial.println(MOTOR_A_IN2);
  Serial.print("Motor B: IN1=");
  Serial.print(MOTOR_B_IN1);
  Serial.print(", IN2=");
  Serial.println(MOTOR_B_IN2);
  
  ledcAttachPin(MOTOR_A_IN1, 0);
  ledcAttachPin(MOTOR_A_IN2, 1);
  ledcAttachPin(MOTOR_B_IN1, 2);
  ledcAttachPin(MOTOR_B_IN2, 3);
  
  // Initialize motors in stopped state
  Serial.println("Initializing motors in stopped state");
  stopMotors();
  
  // Short delay to ensure PWM channels are properly initialized
  delay(100);
  Serial.println("Motor setup complete");
}

void moveForward() {
  Serial.println("Motor control: FORWARD");
  // Motor A forward
  ledcWrite(0, MOTOR_SPEED_ACTUAL);  // IN1
  ledcWrite(1, 0);                   // IN2
  
  // Motor B forward
  ledcWrite(2, MOTOR_SPEED_ACTUAL);  // IN1
  ledcWrite(3, 0);                   // IN2
}

void moveBackward() {
  Serial.println("Motor control: BACKWARD");
  // Motor A backward
  ledcWrite(0, 0);                   // IN1
  ledcWrite(1, MOTOR_SPEED_ACTUAL);  // IN2
  
  // Motor B backward
  ledcWrite(2, 0);                   // IN1
  ledcWrite(3, MOTOR_SPEED_ACTUAL);  // IN2
}

void turnLeft() {
  Serial.println("Motor control: TURN LEFT");
  // Motor A backward
  ledcWrite(0, 0);                   // IN1
  ledcWrite(1, MOTOR_SPEED_ACTUAL);  // IN2
  
  // Motor B forward
  ledcWrite(2, MOTOR_SPEED_ACTUAL);  // IN1
  ledcWrite(3, 0);                   // IN2
}

void turnRight() {
  Serial.println("Motor control: TURN RIGHT");
  // Motor A forward
  ledcWrite(0, MOTOR_SPEED_ACTUAL);  // IN1
  ledcWrite(1, 0);                   // IN2
  
  // Motor B backward
  ledcWrite(2, 0);                   // IN1
  ledcWrite(3, MOTOR_SPEED_ACTUAL);  // IN2
}

void stopMotors() {
  Serial.println("Motor control: STOP");
  // Stop both motors
  ledcWrite(0, 0);
  ledcWrite(1, 0);
  ledcWrite(2, 0);
  ledcWrite(3, 0);
}

void setDirection(MotorDirection direction) {
  switch (direction) {
    case FORWARD:
      moveForward();
      break;
    case BACKWARD:
      moveBackward();
      break;
    case TURN_LEFT:
      turnLeft();
      break;
    case TURN_RIGHT:
      turnRight();
      break;
    case STOP:
    default:
      stopMotors();
      break;
  }
}

// No longer used - GPIO39 is handled in main.cpp
void toggleAuxPin() {
  // Empty implementation - kept for API compatibility
} 

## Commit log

2025-03-05 PWM speed controll, code more modular
2025-03-13 changes to wiring
2025-04-08 added pcb project
    [stone_pcb_v1.kicad_pcb, stone_pcb_v1.kicad_sch]
2025-04-09 modified pcb
    [stone_pcb_v1.kicad_pcb, stone_pcb_v1.kicad_sch]
2025-04-09 changes to pcb
    [stone_pcb_v1.kicad_pcb]
2025-04-14 finished pcb design
    [stone_pcb_v1.kicad_pcb, stone_pcb_v1.kicad_sch]
2025-04-14 updated pcb
    [stone_pcb_v1.kicad_pcb]
2025-05-10 added v5, motor direction test
